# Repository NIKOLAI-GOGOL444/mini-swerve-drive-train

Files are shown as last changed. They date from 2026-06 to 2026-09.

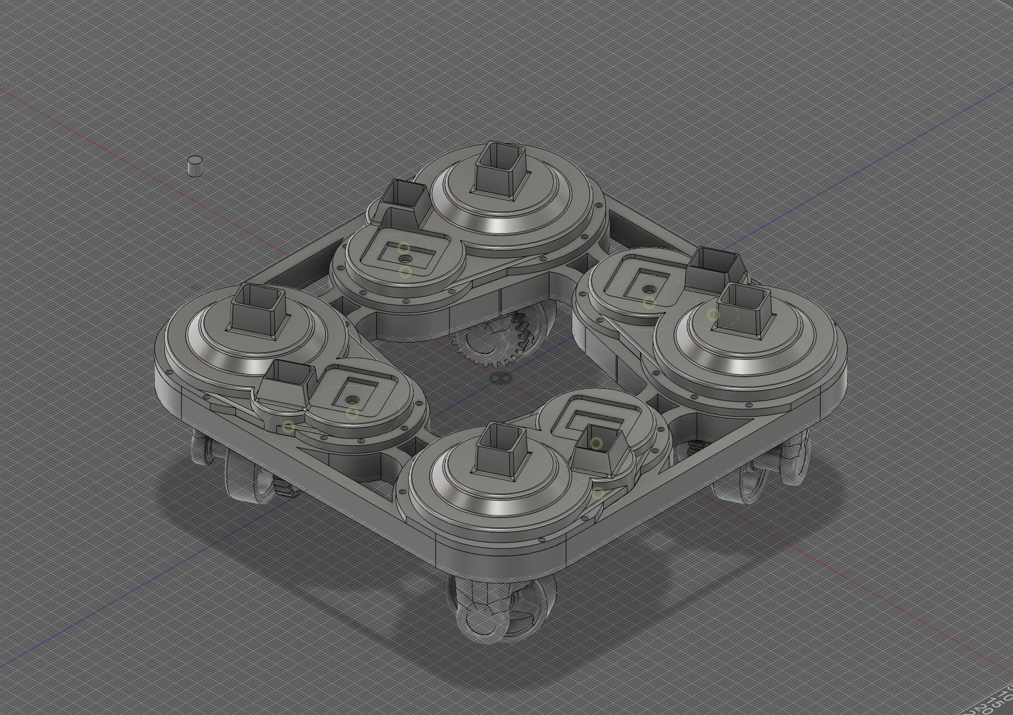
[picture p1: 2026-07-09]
images: demos/Screenshot 2026-07-07 at 9.57.56 PM.jpeg

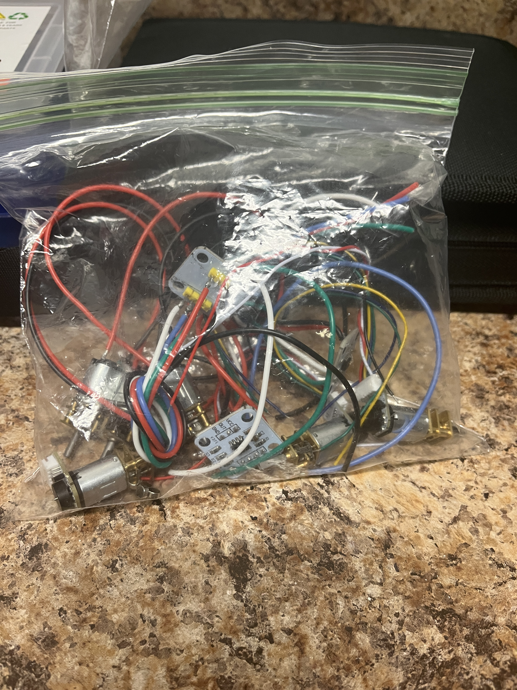
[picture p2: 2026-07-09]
images: demos/IMG_0874.jpeg

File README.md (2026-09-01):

IMPORTANT NOTE FOR OUTPOST REVIEWERS: please ignore the pcb stuff in my BOM.CSV and files and stuff. I do not have a pcb design yet, so I will not be requesting funding for that part of this project, and will request for it as a sepreate project at a later time. 
NEW NOTE: I have edited the BOM.csv file to exclude pcb stuff. 

IMPORTANT NOTE FOR HORIZONS REVIEWERS:
NOTE: i am ONLY trying to submit the CONTROLLER pcb right now. all my hours have been working on that, do not reject my project under the robot pcb stuff not being in here, thats because it isnt finished yet, ill submit that at a later date, just worry about the controller stuff. 
UPDATE: as of tuesday july 28 1:18 am, I have finished the controller pcb and uploaded the final designs file to the repo. it is now ready to be purchased.
Screenshot 2026-07-28 at 10 36 25 AM
Screenshot 2026-07-28 at 10 36 18 AM
Screenshot 2026-07-28 at 10 37 19 AM
8/31/26 UPDATE
after more work, I have resubmitted for hour aproval. since my last update to this repo, I have ordered my finished boards for manufacturing and recieved them in the mail. here are some images. I have begun assembly, first by harvesting some chips from old devboards and breakout modules. after that I hit a wall when I realized that salvaging tiny capacitors and resistors would be impossible, so now I am working on getting all my parts ordered so I can assemble. hopefully I get my hours aprovved soon so I can buy digikey grants, because that would seriously help me greatly. 




UPDATE: as of monday july 27th 11:36 pm, I have uploaded new gerbers that are of the pcb fully routed and corrected against the DRC. if wanted, the pcb could now be purchased and it would function, but the silkscreen labels would be a mess. im now going to arrange the silkscreen, then begin on the swerve drive brain pcb. 
NEW NOTE AFTER SECOND REJECTION: 
my pcb wasnt routed yet because this project is currently a work in progress. I am submitting it fairly early on because I want to qualify intime to go to horizons polaris (I have an extension to qualify until july 31st.) I have done work on my pcb and almost finished the routing, it is pretty close to done, just gotta double check everything and fix some small issues. just please understand that this pcb and its gerber files arent finsished, which explains the missing routing and anything you may find in this file. I am actively working on this project, so please give me grace with any structural errors that may be in the pcb and help me make the polaris deadline. im attaching the newer gerbers. 
my project for horizons is the pcbs that go with this robot, I am submitting them as a seperate hardware project that I will not need funding for. I am documenting my hours for the pcbs seperate from the code file I used on the robots cad and coding, however I will be using the same github for both projects just to keep things simple. so ignore all the cad and code stuff, and just look at the PCB stuff, because thats my horizons project. I am currently in the process of tracing the controller PCB, so all I have right now as I submit is the schematic and maybe a unfinished gerber file, but I will keep working on the project and add to my repo as I go. if you have any questions just reach me on the hackclub slack. 
ALSO, the BOM.CSV you see when you open my repo isnt the one for this project, that is for my outpost project. please look in my controller pcb stuff file, you will find my horizons BOM.CSV file in there. 
STEPS TO REPRODUCE:
when pcbs are finished, someone can recreate my PCBS by going online to a pcb manufacturing website, uploading the gerber files for my controller and robot control board I will eventually put in my repo, and ordering them, then either choosing to assemble the pcbs themselves or buying it preassembled. if they wanted recreate the FULL ROBOT (NOT INCLUDED WITH MY HORIZONS SUBMISSION, INCLUDING FYI) they would then flash the code in my repo to their PCBs, then 3d print the cad files with either their own 3d printer or through a manufacturing sight, assembling based off of the cad images ive attached for the project (i think I will add an assembly tutorial eventually), then plugging in batteries and then they would have my robot! 
NEWER 3D RENDERS AND PCB EDITOR SCREENSHOTS AS OF SUN JUL 26 2026
Screenshot 2026-07-26 at 7 36 01 PM
Screenshot 2026-07-26 at 7 36 13 PM
Screenshot 2026-07-26 at 7 39 59 PM

3D RENDERS (PLEASE NOTE THAT THE CONTROLLER PCB ISNT FINISHED, AND I HAVENT STARTED THE ROBOT PCB.[swervecontrollerPCBv1.pdf](https://github.com/user-attachments/files/30342656/swervecontrollerPCBv1.pdf)
Screenshot 2026-07-23 at 6 22 36 AM
Screenshot 2026-07-24 at 6 09 05 AM
Screenshot 2026-07-24 at 6 09 14 AM

hi!

im making a mini swerve drive train inspired by FRC swerve drive trains, because they just make me so happy lol.
if you cant tell already idk how to use github at all.
I hope to figure it out as I work on this project. 
if you need anything or have any questions about my project, id be happy to help! just contact me however that works on git idk.

thank you for your time,
-NIKOLAI!
# Mini Swerve Drive Train

inspired by my love of FRC swerve modules and drive trains, they're so freaking cool. 
this project is documented on forge, stardance, and horizons. 
I would most reccomend checking out stardance, because that is where this project is most actively docdumented. 
https://stardance.hackclub.com/projects/25609
ive logged around 25 hours as I write this, however I only began logging maybe two weeks ago, and in reality this project has taken MUCH much longer than that lol. 

AI declaration for hackclub

I worked with claude to turn my google docs parts list into a BOM.CSV file. I also use gemini or other chatbots to help me write code and understand data protocols. I never copy and paste exactly what is given to me without understanding what it is or why, but instead use AI as a learning tool to help me better learn and understand programming. especially as a new programmer, I am entirely self taught using online resources, and AI has been a very useful tool for my learning. 

here is a 3d demo of my cad, stl files are available in this repository. 

https://a360.co/4gOPGcb

Screenshot 2026-07-09 at 3 30 32 AM

Screenshot 2026-07-09 at 3 30 18 AM

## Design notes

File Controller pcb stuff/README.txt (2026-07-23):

the gerber files for the controller are currently unfinished! just putting them here so I can have something for horizons reviewers, will update when it is finished.

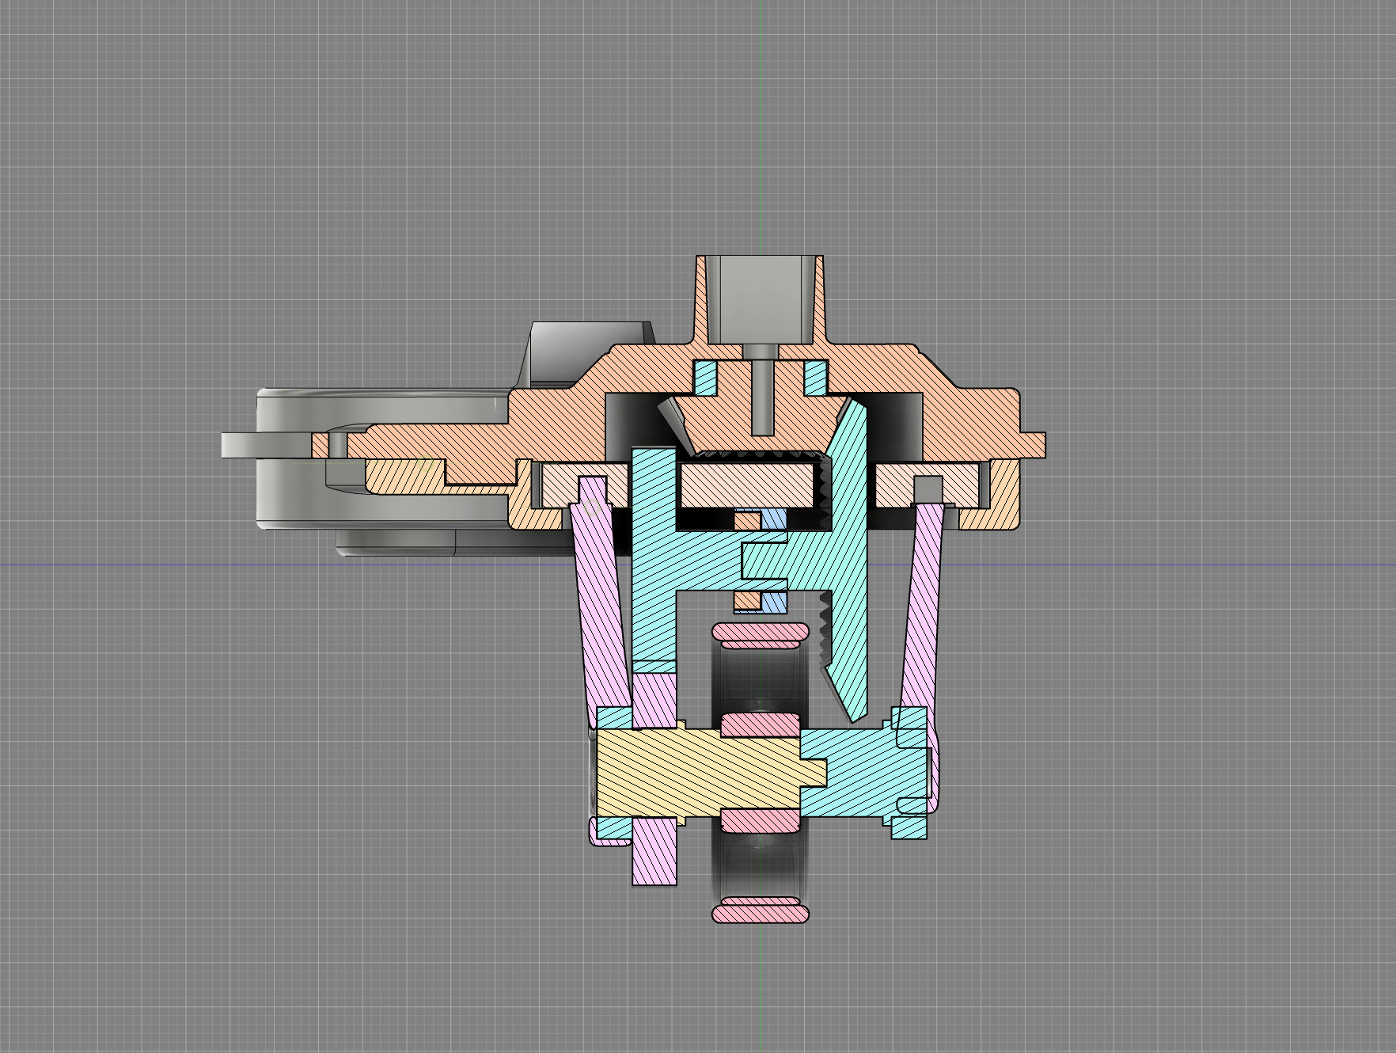
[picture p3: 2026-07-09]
images: demos/Screenshot 2026-07-06 at 1.36.42 AM.jpeg

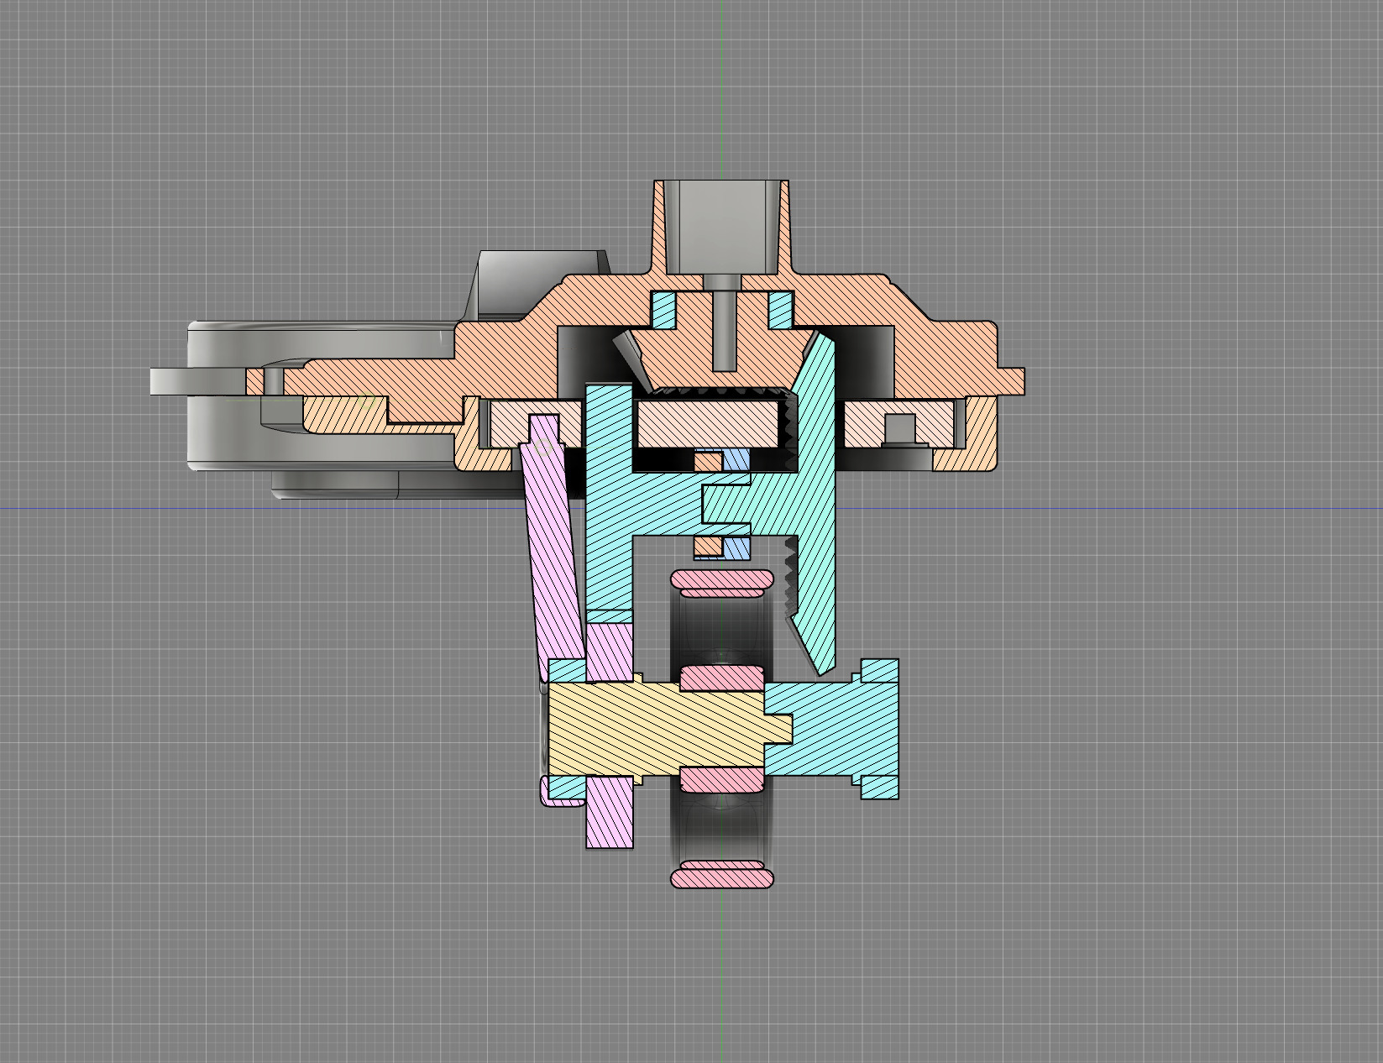
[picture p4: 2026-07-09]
images: demos/Screenshot 2026-07-06 at 1.37.23 AM.jpeg

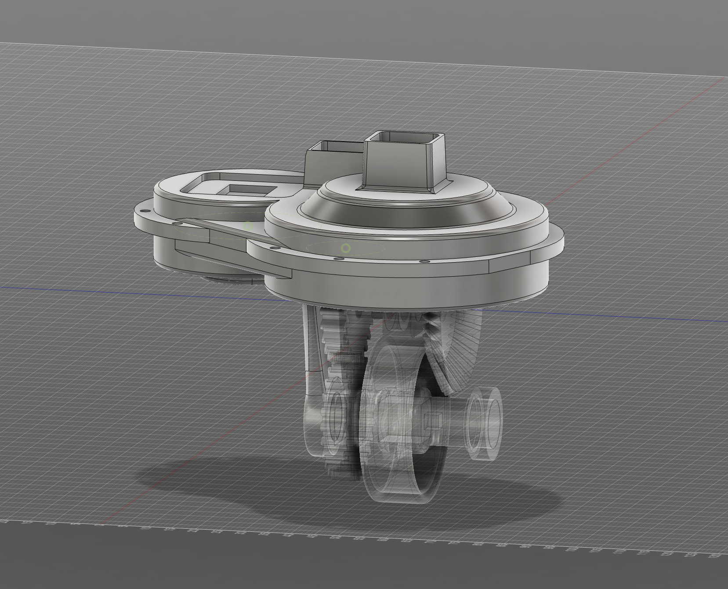
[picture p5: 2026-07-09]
images: demos/Screenshot 2026-07-06 at 1.37.53 AM.jpeg

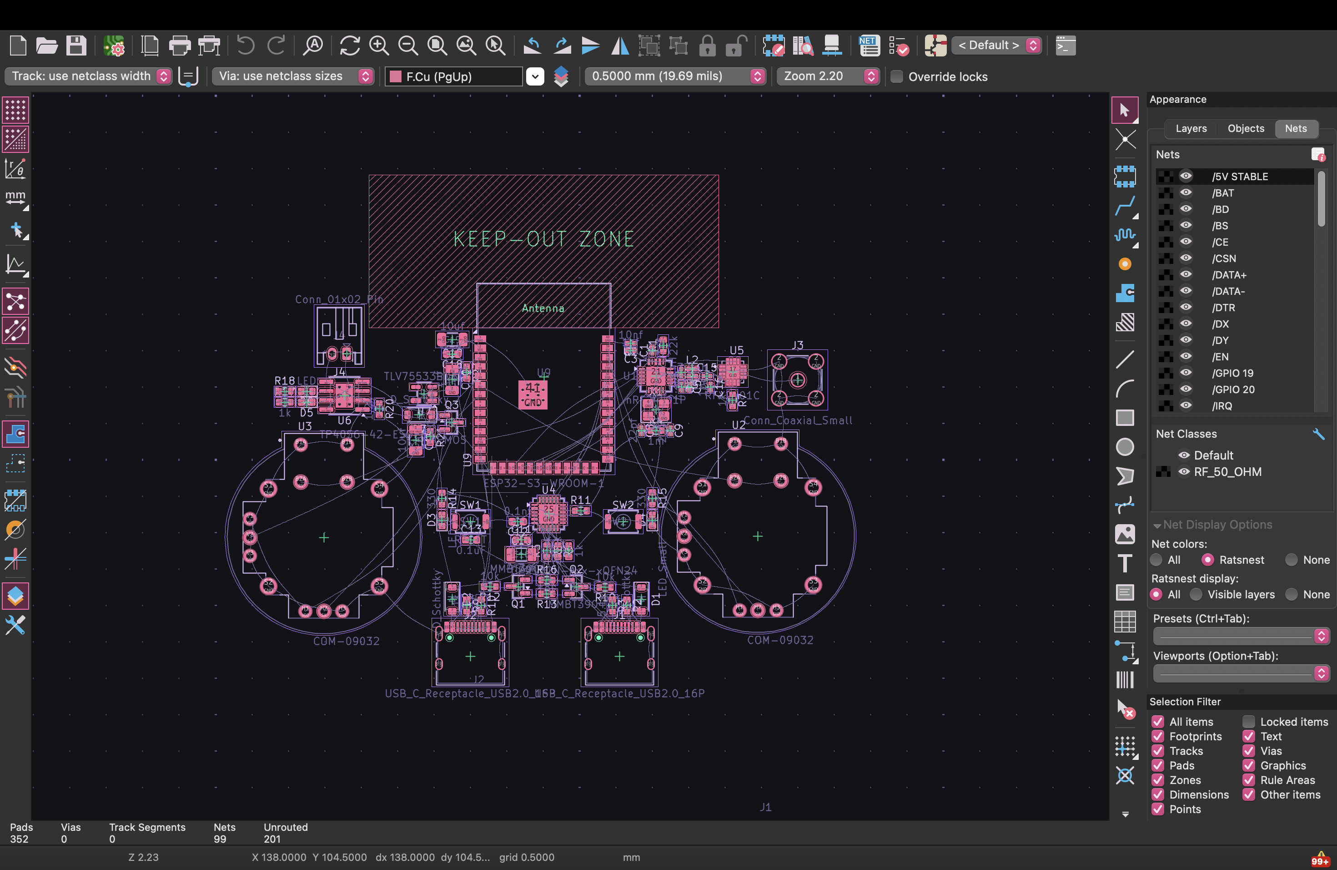
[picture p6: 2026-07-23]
Controller pcb stuff/current state of controller pcb.png

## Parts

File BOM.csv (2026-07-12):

Category | Item | Voltage | Scope | Qty | Est. Unit Price | Est. Total Price | Source Link | Notes
Compute | ESP32-S3-DevKitC-1 N16R8 dev board | 3.3V logic / 5V USB | Central x1 | 1 | 16.99 | 16.99 | https://www.amazon.com/dp/B0DKF4DSQ4 | Main controller
Sensing | TCA9548A 8-Channel I2C Multiplexer breakout | 3.3V | Central x1 | 1 | 8.49 | 8.49 | https://www.amazon.com/dp/B0FBGC5BRP | Needed since 4x steer encoders likely share default I2C address
Sensing | MPU-6050 Gyroscope/Accelerometer breakout (GY-521) | 3.3V | Central x1 | 1 | 6.99 | 6.99 | https://www.amazon.com/dp/B01DK83ZYQ | Confirm logic-out is 3.3V
Power | 7.4V 2S LiPo battery (2200-3000mAh, XT60) | 7.4V | Central x1 | 1 | 19.99 | 19.99 | (generic - link not provided) | Feeds drive+steer controllers; needs step-down to 3.3V for logic
Drive | Drive motor w/ encoder | 7.4V motor / 3.3V encoder | Per module | 4 | 12.00 | 48.00 | https://www.amazon.com/dp/B0GSJSMNC9 | Do not backfeed 3.3V encoder line into 7.4V motor leads
Drive | Drive motor controller breakout (DRV8833-class) | 7.4V in / logic PWM in | Per module | 4 | 9.99 | 39.96 | https://www.amazon.com/dp/B0DX6BNV53 | Sold as 5-pack (1 spare). Check board's logic-input voltage tolerance vs ESP32 3.3V GPIO
Steer | Steer motor | 7.4V | Per module | 4 | 9.50 | 38.00 | (Amazon cart link not resolvable) | Same controller family as drive
Steer | Steer shaft encoder breakout (AS5600-style) | 3.3V, I2C | Per module | 4 | 7.49 | 29.96 | https://www.amazon.com/dp/B0CM3C8KFT | Goes through TCA9548A mux
Bearings | 6900-2RS bearing (10x22x6mm, large) | N/A | Per module | 4 | 1.10 | 4.40 | https://www.amazon.com/dp/B0CRLFSLWP | ASSUMPTION: 1/module - confirm vs your CAD
Bearings | 10x15x4mm bearing (smaller) | N/A | Per module | 4 | 1.05 | 4.20 | https://www.amazon.com/dp/B0DJQFKSBZ | ASSUMPTION: 1/module
Bearings | MR105-2RS bearing (5x10x4mm, even smaller) | N/A | Per module | 4 | 0.85 | 3.40 | https://www.amazon.com/dp/B082PRVZ7B | ASSUMPTION: 1/module
Bearings | 7mm ID bearing, inner drive mechanism | N/A | Per module | 4 | 1.10 | 4.40 | https://www.amazon.com/dp/B0F4XYQ2KP | ASSUMPTION: 1/module
Fabrication | 3D printing filament (chassis + 4x module housings/lids) | - | Central | 1 | 25.00 | 25.00 | - | ~700g-1kg PETG/PLA, own printer

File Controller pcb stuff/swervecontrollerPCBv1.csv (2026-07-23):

Reference | Qty | Value | DNP | Exclude from BOM | Exclude from Board | Footprint | Datasheet
C1 | 1 | 33nf |  |  |  | Capacitor_SMD:C_0402_1005Metric
C2 | 1 | 10nf |  |  |  | Capacitor_SMD:C_0402_1005Metric
C3 | 1 | 1nf |  |  |  | Capacitor_SMD:C_0402_1005Metric
C4 | 1 | 2.2nf |  |  |  | Capacitor_SMD:C_0402_1005Metric
C5 | 1 | 4.7pf |  |  |  | Capacitor_SMD:C_0402_1005Metric
C8,C9 | 2 | 22pf |  |  |  | Capacitor_SMD:C_0402_1005Metric
C10 | 1 | 4.7uf |  |  |  | Capacitor_SMD:C_1206_3216Metric
C11,C18 | 2 | 0.1uf |  |  |  | Capacitor_SMD:C_0603_1608Metric
C12 | 1 | 0.1nf |  |  |  | Capacitor_SMD:C_0603_1608Metric
C13 | 1 | 0.1uF |  |  |  | Capacitor_SMD:C_0603_1608Metric
C14,C19 | 2 | 10uf |  |  |  | Capacitor_SMD:C_1206_3216Metric
C15 | 1 | 1.5pF |  |  |  | Capacitor_SMD:C_0402_1005Metric
C16 | 1 | 1pF |  |  |  | Capacitor_SMD:C_0402_1005Metric
C20 | 1 | 1uf |  |  |  | Capacitor_SMD:C_1206_3216Metric
D1,D2,D7 | 3 | D_Schottky |  |  |  | Diode_SMD:D_SOD-123
D3,D4 | 2 | LED_Small |  |  |  | LED_SMD:LED_0603_1608Metric
D5,D6 | 2 | LED |  |  |  | LED_SMD:LED_0603_1608Metric
J1,J2 | 2 | USB_C_Receptacle_USB2.0_16P |  |  |  | Connector_USB:USB_C_Receptacle_HRO_TYPE-C-31-M-12 | https://www.usb.org/sites/default/files/documents/usb_type-c.zip
J3 | 1 | Conn_Coaxial_Small |  |  |  | Connector_Coaxial:SMA_Amphenol_901-144_Vertical
J4 | 1 | Conn_01x02_Pin |  |  |  | Connector_JST:JST_PH_S2B-PH-K_1x02_P2.00mm_Horizontal
L1 | 1 | 8.2nH |  |  |  | Inductor_SMD:L_0402_1005Metric
L2 | 1 | 2.7nh |  |  |  | Inductor_SMD:L_0402_1005Metric
L3 | 1 | 3.9nh |  |  |  | Inductor_SMD:L_0402_1005Metric
Q1,Q2 | 2 | MMBT3904 |  |  |  | Package_TO_SOT_SMD:SOT-23 | https://www.onsemi.com/pdf/datasheet/pzt3904-d.pdf
Q3 | 1 | PMOS |  |  |  | Package_TO_SOT_SMD:SOT-23 | https://ngspice.sourceforge.io/docs/ngspice-html-manual/manual.xhtml#cha_MOSFETs
R1 | 1 | 22k |  |  |  | Resistor_SMD:R_0603_1608Metric
R2,R3,R9,R10 | 4 | 5.1k |  |  |  | Resistor_SMD:R_0603_1608Metric
R4 | 1 | 1m |  |  |  | Resistor_SMD:R_0603_1608Metric
R5 | 1 | 22.1k |  |  |  | Resistor_SMD:R_0603_1608Metric
R6 | 1 | 47.5k |  |  |  | Resistor_SMD:R_0603_1608Metric
R7,R8,R17,R18 | 4 | 1k |  |  |  | Resistor_SMD:R_0603_1608Metric
R11,R12,R13,R16,R19,R23 | 6 | 10k |  |  |  | Resistor_SMD:R_0603_1608Metric
R14,R15 | 2 | 330 |  |  |  | Resistor_SMD:R_0603_1608Metric
R20 | 1 | 1.2k |  |  |  | Resistor_SMD:R_0603_1608Metric
R21 | 1 | 100k |  |  |  | Resistor_SMD:R_0603_1608Metric
SW1 | 1 | RESET |  |  |  | Button_Switch_SMD:SW_Push_SPST_NO_Alps_SKRK
SW2 | 1 | BOOT |  |  |  | Button_Switch_SMD:SW_Push_SPST_NO_Alps_SKRK
U1 | 1 | nRF24L01P |  |  |  | Package_DFN_QFN:QFN-20-1EP_4x4mm_P0.5mm_EP2.5x2.5mm | http://www.nordicsemi.com/eng/content/download/2726/34069/file/nRF24L01P_Product_Specification_1_0.pdf
U2,U3 | 2 | COM-09032 |  |  |  | COM-09032:XDCR_COM-09032
U4 | 1 | CP2102N-Axx-xQFN24 |  |  |  | Package_DFN_QFN:QFN-24-1EP_4x4mm_P0.5mm_EP2.6x2.6mm | https://www.silabs.com/documents/public/data-sheets/cp2102n-datasheet.pdf
U5 | 1 | RFX2401C |  |  |  | RFX2401C:QFN50P300X300X60-17N
U6 | 1 | TP4056-42-ESOP8 |  |  |  | Package_SO:SOIC-8-1EP_3.9x4.9mm_P1.27mm_EP2.41x3.3mm_ThermalVias | https://www.lcsc.com/datasheet/lcsc_datasheet_2410121619_TOPPOWER-Nanjing-Extension-Microelectronics-TP4056-42-ESOP8_C16581.pdf
U7 | 1 | TLV75533PDBV |  |  |  | Package_TO_SOT_SMD:SOT-23-5 | http://www.ti.com/lit/ds/symlink/tlv755p.pdf
U9 | 1 | ESP32-S3-WROOM-1 |  |  |  | RF_Module:ESP32-S3-WROOM-1 | https://www.espressif.com/sites/default/files/documentation/esp32-s3-wroom-1_wroom-1u_datasheet_en.pdf
X1 | 1 | 16mhz |  |  |  | Crystal:Crystal_SMD_3225-4Pin_3.2x2.5mm

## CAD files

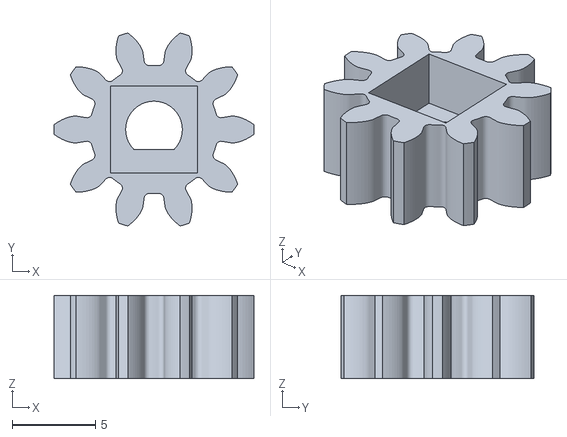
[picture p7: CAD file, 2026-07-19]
swerves v6/fixed 10t.stl
12.0 x 11.6 x 5.00

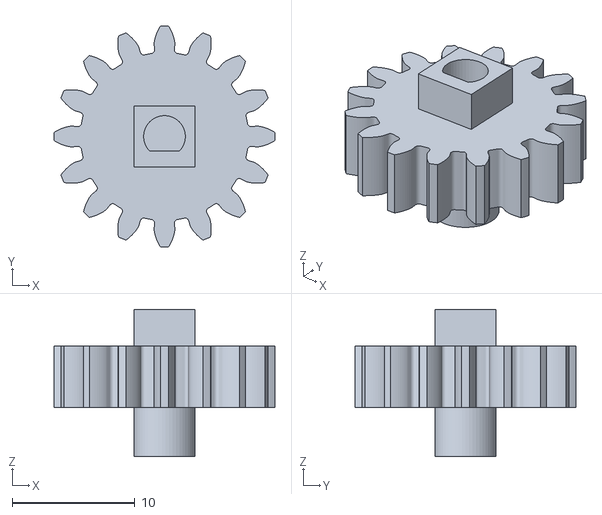
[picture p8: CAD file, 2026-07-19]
swerves v6/16t fixed.stl
18.0 x 18.0 x 12.0

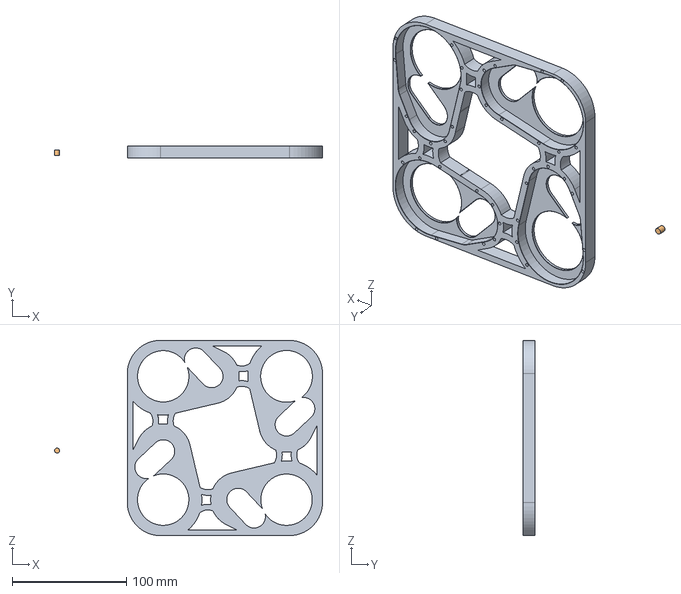
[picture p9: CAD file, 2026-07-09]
swerves v6/chasiss v1.step
234.7 x 10.5 x 171.0 mm

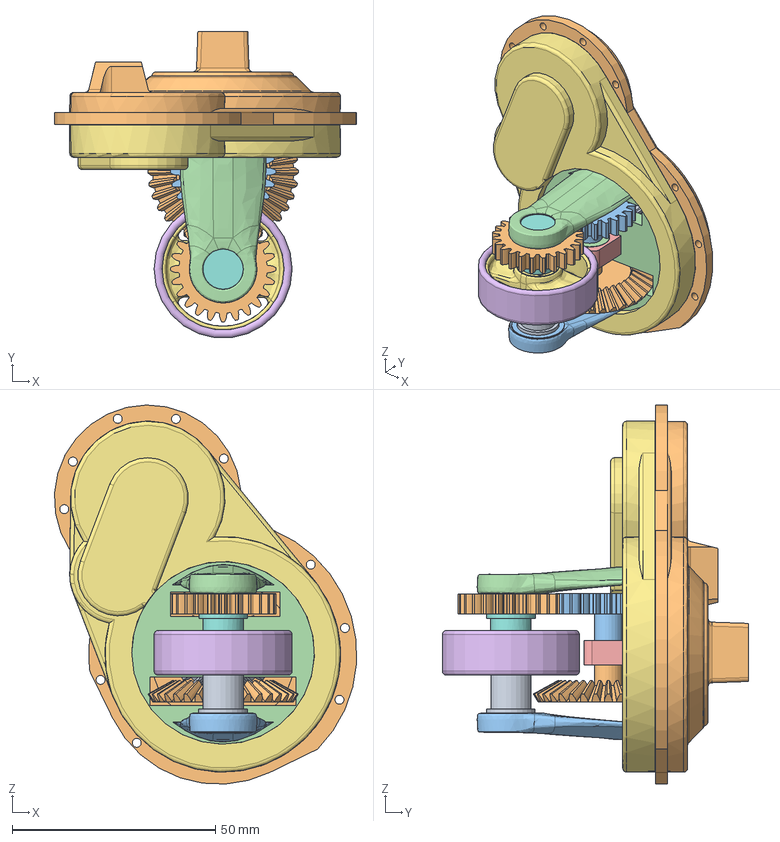
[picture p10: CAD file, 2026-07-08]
swerves v6/REAL swerves V6.step
74.4 x 75.4 x 93.3 mm

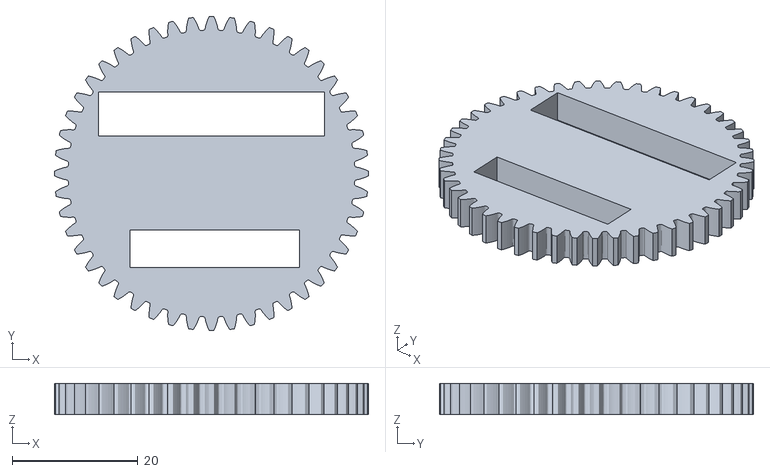
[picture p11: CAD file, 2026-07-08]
swerves v6/48t steer V^.stl
50.0 x 50.0 x 5.00

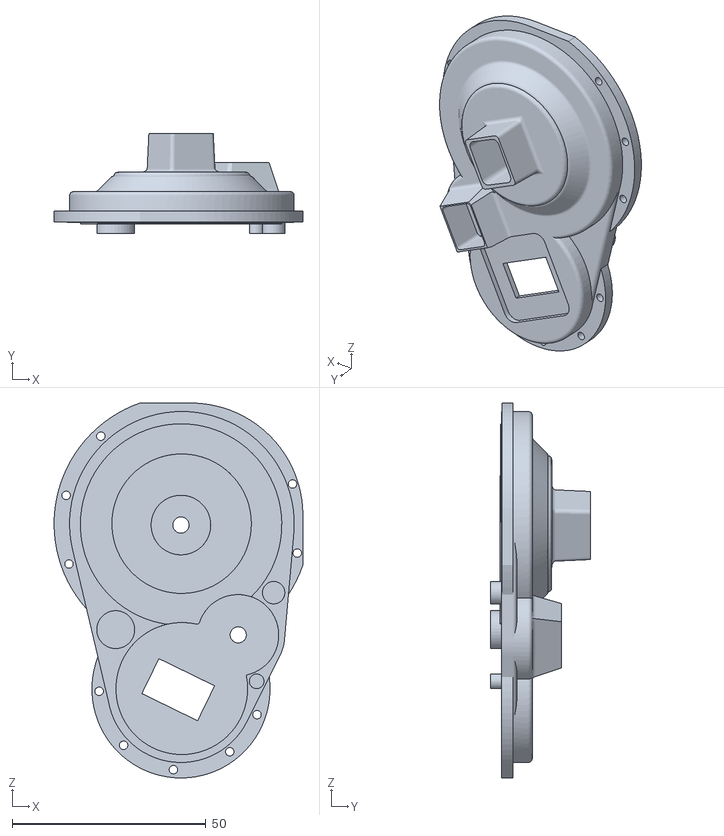
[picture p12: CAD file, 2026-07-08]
swerves v6/top shell v6.stl
64.2 x 25.8 x 96.8

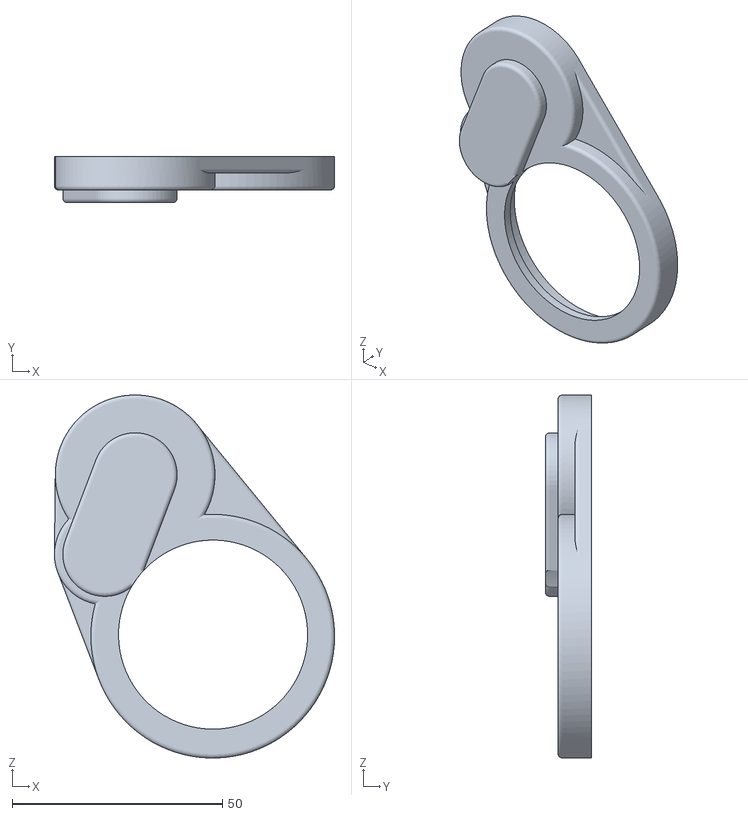
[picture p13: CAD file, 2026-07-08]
swerves v6/bottom shell swerves v6.stl
66.7 x 11.0 x 86.4

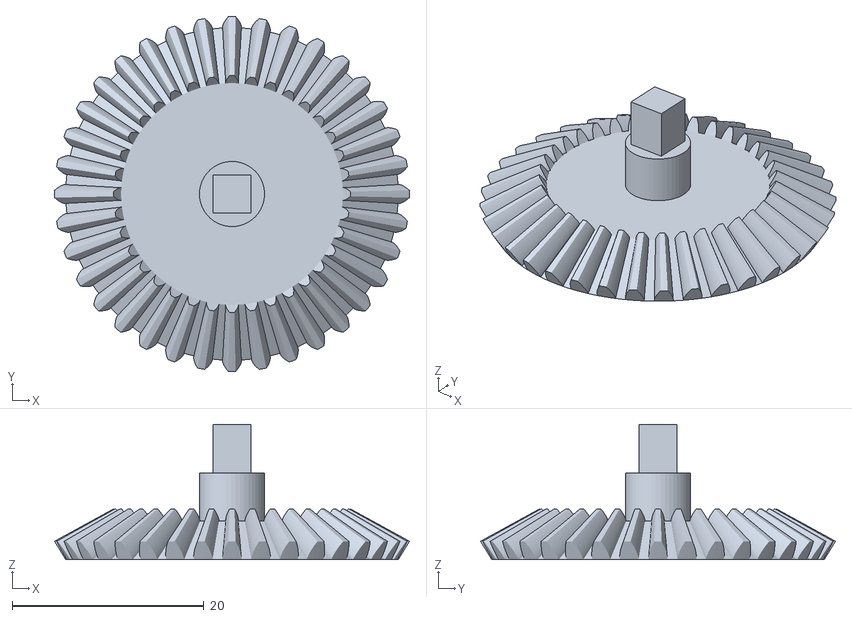
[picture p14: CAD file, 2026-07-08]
swerves v6/updated 36t gear.stl
37.0 x 37.0 x 14.1

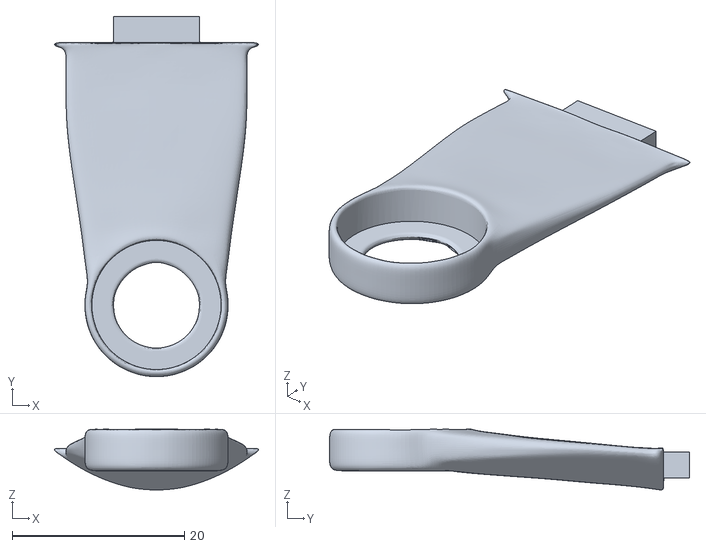
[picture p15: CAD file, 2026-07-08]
swerves v6/stick 2 V6.stl
23.7 x 41.8 x 7.07

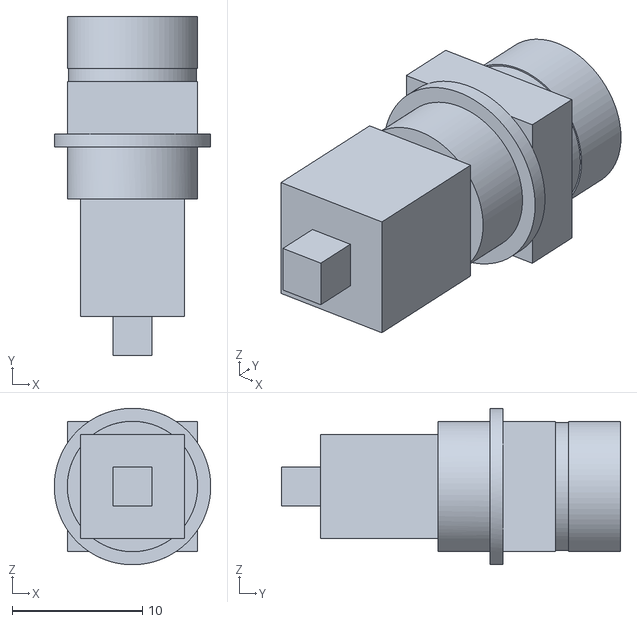
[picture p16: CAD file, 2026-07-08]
swerves v6/drive tube peg v6.stl
12.0 x 26.0 x 12.0

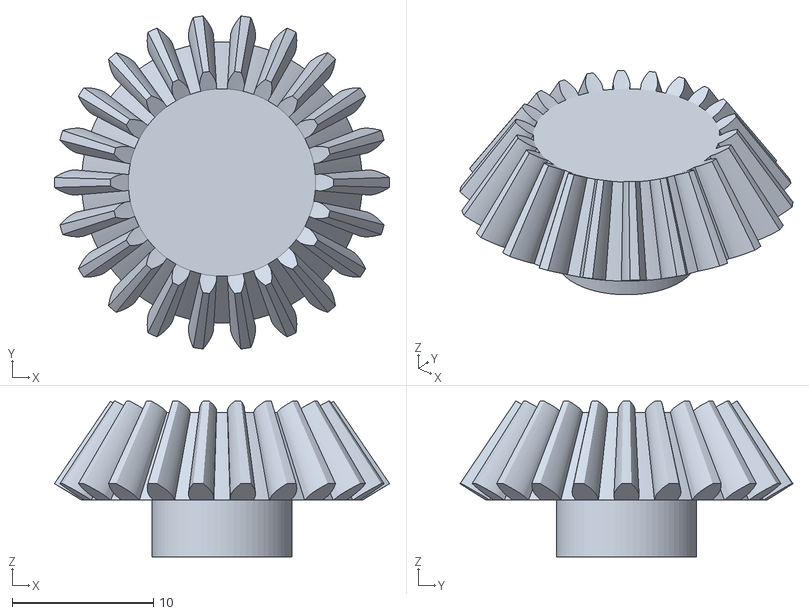
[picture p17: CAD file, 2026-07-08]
swerves v6/22tt.stl
23.7 x 23.6 x 11.0

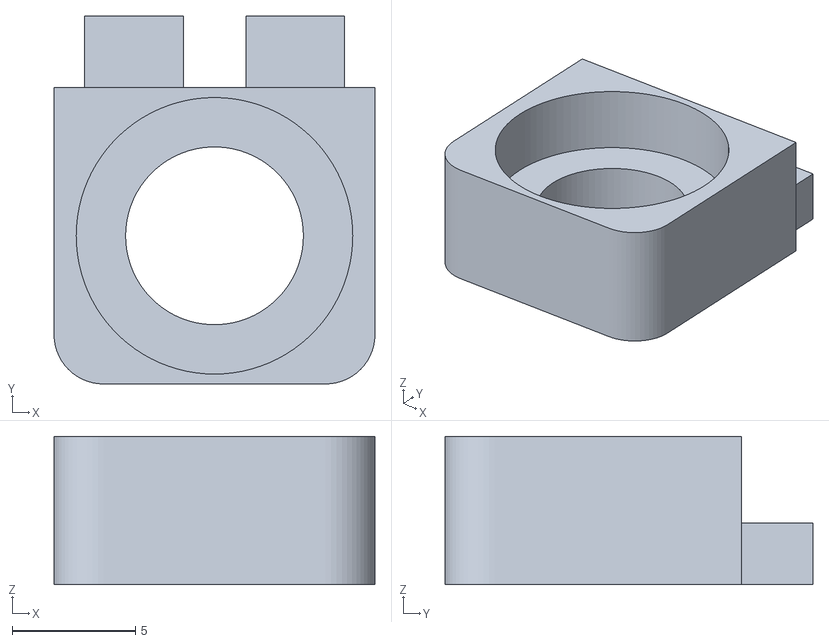
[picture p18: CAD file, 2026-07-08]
swerves v6/hole v3.stl
13.0 x 14.9 x 6.00

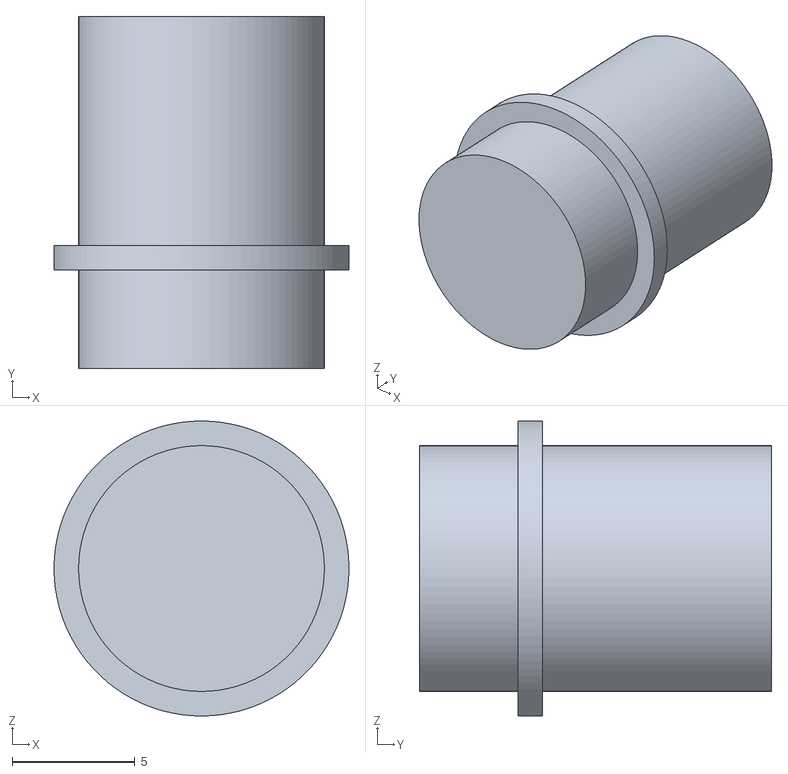
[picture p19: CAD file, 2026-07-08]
swerves v6/drive tube hole v6.stl
12.0 x 14.3 x 12.0

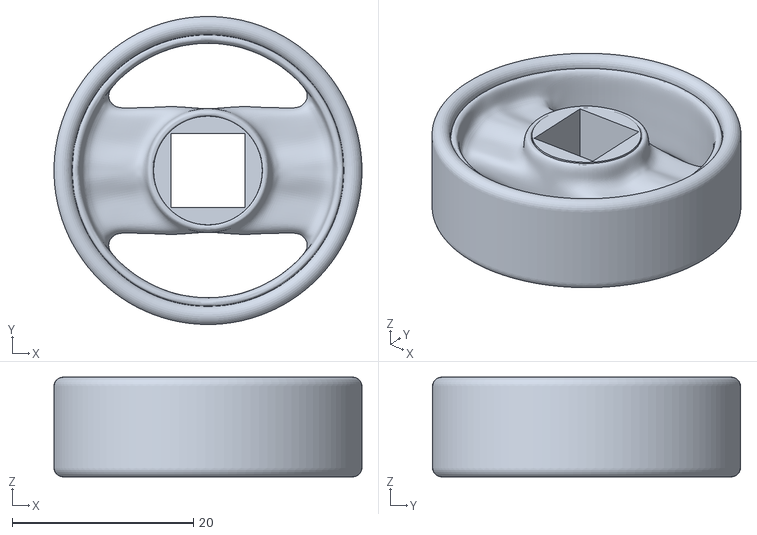
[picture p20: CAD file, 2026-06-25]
swerves v6/wheel v6.stl
34.0 x 34.0 x 11.0

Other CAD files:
swerves v6/stick v6.stl
swerves v6/drive attached gear v6.stl
swerves v6/16t v6.stl
swerves v6/30t v6.stl
swerves v6/10t v6.stl
swerves v6/REAL swerves V6.stl

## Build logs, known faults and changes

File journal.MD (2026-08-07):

all logs from forge that predate my stardance documentation are here! if you want to see more recent logs, please visit my stardance page. the link to that is in the readme.md file. 

FOR HORIZONS REVIEWERS
https://lapse.hackclub.com/user/@nikolai_gogol444
that is the link to my lapse page. all pcb time lapses are easily found beacause they are conviniently named. the EARLIEST time lapse that Is part of my horizons project and is documented on the code file that I am attaching my horizons time lapses to is schematic design from july 20, 2026 at 3:22am. any timelapse that predates that Is asociated with my stardance project and can be ignored. I Will start documenting journal entries for my horizons project here.
ENTRY 2 FRIDAY AUG 7
NOTE: for some reason images arent working right now, I will update my repo later with images of the pcbs, all my files are in though
alot of work since my last entry! after tracing the 50 ohm traces on my controller, I ran it against the DRC and fixed any issues that came up, then I organized the silkscreens, and added some decals! here is the finished pcb design, that is available in the controller pcb stuff file. 
for some reason I cannot paste the image, so I will be putting images in their respective files.
after that, I began working on the controller pcb. I reused the schematic for my controller, then deleted the joysticks and battery setup, and kept the things like the rf schematic that I would need for my controll pcb. this pcb required me to keep within a tight 52 by 52 mm square in order to fit in the chasis of my robot. I acheived this by being clever with part placement, optimizing my esp chips pinout and using the backside of my pcb. my pcb includes a mpu6050, a tca multiplexer, test points to connect to my motors and encoders, drv8833 motor drivers, usbc ports for serial data and flashing, and a charge system that allows power to come from either the battery or the usbc ports, and steps down some of that voltage to 3.3v to run logic parts. I used a 4 layer pcb to better isolate the rf signal, and allow for two signal planes. I plan to purchase these pcbs from pcbbuy using my own money when I get the chance. 

ENTRY 1:
I didnt know I was supposed to do journal entries, so Ill do one big one here to document the past 3 or so days of pcb work, and go consistently from there.
I first began by doing a quick 20 minute KICAD tutorial video, as I do before using any new software, to figure out how to use it. then, I just kind of began working and learning the software on the way. I started by looking up schematics for the breakout boards that I had used to breadboard my project, so I could figure out what chips and components id need. I then went to the data sheet for the chips and replicated the ideal pcb setups shown in each datasheet on my board, and using google gemini for input and questions as I went. I wouldnt reccomend entirely trusting AI to help with pcb design, because It was very hard getting the AI to interpret my schematic correctly, and it would identify things that were perfectly fine as errors, vice versa. after that, I had a complete controller schematic with two joysticks, a 2.4ghz RF system based on the NRF24L01 PA LNA breakout board, a power distribution system that charges a 3.7v li po battery from onboard usbc ports I included for charging, serial data and code flashing, and powers the board using said battery, and boot and reset buttons. a picture of my schematic is available in the controller pcb stuff file. 
I then went to begin routing, when I got some errors, which I eventually solved by adding pads that were missing in the schematics, usually EPADs and ground pads, and routing them to where they were supposed to go, and changing my ESP32 S3 WROOM N16R8 schematic to the generic ESP32 S3 WROOM 1 schematic, which was identical to the custom footprint I got on the internet and was native to KICAD, which fixed the errors. I then began organizing my components on the board, and today I will be designing the trace on the RF stuff on the board to have exactly 50 OHMs of resistance and routing all my components, new entry coming soon. 

# 2026-06-25: some pretty important CAD fixes, and a chasis!

hi! I finally did the final changes on CAD, im pretty sure, ill know if theyre perfect when I print the fixed parts, should work though cad looks good. 

I fixed the CAD issues previously stated in a earlier post, which included the uncentered bevel gear, loosely meshed drive gears, and loosely meshing bevel gear in the drive system. all the gears in fusion mesh properly now, and the meshing is good in the drive bevel system at all rotations, I just made sure. Im going to update the GITHUB fusion files. 

also, I made a chasis for my swerve modules. its made to be pretty lightweight, as this whole project is, Im trying to stay under 3lbs. one swerve module including electronics is 3.7 oz, and the chasis is 2.1 oz, so im well below that weight limit currently. I will also include the chasis in the new    CAD update. 
Screenshot 2026-06-25 at 12.38.27 AM.png

Screenshot 2026-06-25 at 12.35.18 AM.png

# 2026-06-17: origins

I thought it would be a good idea to mention how I started this project, as I only started documenting it here once I heard about this website. my first steps were going to the fab shop at robotics club, and looking at swerve modules, aswell as taking photos and videos. I moved around the wheel and rolled it, to get a better understanding of the mechanisms that allowed for the consecutive steering and driving. I also refrenced 3d models online, and I defenitley reccomend checking out NERDSPARK 9312s nerd swerve modules, their ingenious idea of using two gear sets with the same ratio, but one smaller than the other, to create a equal spinning motion the encoders could measure, is truly revolutionary. prior to cadding my modules, I chose electronics based off of what would be found on a real frc bot, that were also cost effective. I also plan to design a pcb when I have a complete breadboarded system, and plan to keep these parts for breadboarding. 

heres the part list for those who are curious.

esp32 s3 3.3v(3pcs ESP32-S3-DevKitC-1-N16R8 Development Board Integrated 2.4GHz WiFi Bluetooth 5.0 ESP32-S3-WROOM-1 Microcontroller Processor Dual Type C Interface for Arduino)

drive controllers 7.4v (5PCS DC DRV8833CPWR Motor Drive Board 2 Channel 3-10V 1.5A H Bridge DC Gear Motor Driver Controller Small Volume Board for DIY Projects)

drive motors 7.4v from controllers for motors, 3.3v for encoders (FABULETTA 2 Pack N20 Encoder DC Gear Motor 6V Metal High Torque D-Shaft for Robotics GA12-N20 Replacement 160-3000RPM Reduction(500RPM))

steer motors 7.4v from controllers(4X JA12-N20 Model DC 12V 100RPM Torque Mini Motor Silver+Gold)

steer shaft encoders 3.3v(WWZMDiB 4Pcs AS5600 Magnetic Encoder 3.3V 12bit high Precision Magnetic Induction Angle Measurement Sensor Module，Mainly Used to Obtain Information Such as Progressive Motor Speed)

breakout board 3.3v(PCA9548A TCA9548A I2C IIC 8-Channel Multiplexer Breakout Board - 1.65-5.5V 400KHz for Arduino, Address 0x70-0x77)

Gyroscope 3.3v(HiLetgo GY-521 MPU-6050 MPU6050 3 Axis Accelerometer Gyroscope Module 6 DOF 6-axis Accelerometer Gyroscope Sensor Module 16 Bit AD Converter Data Output IIC I2C for Arduino)

Bearings(6900-2RS Deep Groove Bearings, ID 10mm x OD 22mm x Width 6mm Double Rubber Sealed Ball Bearings, Pre-Lubricated (GCr15) Chrome Steel 4pcs)

smaller bearings(20Pcs 6700ZZ Deep Groove Ball Bearings, 10x15x4mm Double Metal Shielded Ball Bearing Chrome Steel P0 Z2, Thin Section Miniature Skateboard Bearings for Industrial Machine, Power Tools)

even smaller bearings(uxcell MR105-2RS Deep Groove Ball Bearings 5mm Inner Dia 10mm OD 4mm Bore Double Sealed Chrome Steel Blue Seal Z2 20pcs)

bearings for inner drive mechanism (uxcell 12Pcs MR117ZZ Small Bearing, 7mm ID 11mm OD 3mm Width Double Shielded Deep Groove Ball Bearings for Electric Motor Skateboards 3D Printer, (ABEC 5))

7.4v lipo battery



# 2026-06-16: code modifications!

after coding the motors to move with joystick input, I came across some issues:

- motors getting too hot
- motors moving when joystick isnt touched
- severe delay between joysticks and motor movement. 

after working with gemini, I was able to solve these issues. 

- setting the motor frequency to 2000 prevented overheating
- first, I calculated the average displacement of the joysticks from the center, when untouched. I used these calculations to create a range, and then programmed my joysticks to output a reading of 2048 when within this range. that helped alot, but I still saw some movement when untouched. I then added cubic math to my motor output, replacing the linear mapping I had previously. this scales the motor movement to a cubic function, this combination eliminated any motor movement when joysticks werent touched.

-to fix the great delay between my joysticks and motors, I did a few changes in my code. 
  - added watchdog timers, to ignore data that takes more than 10 miliseconds to return, to prevent 12c jams. 
  - moved my joystick and motor function calls to the top of my 
    loop function so they would be prioritized
  - changed the read frequency of my sensors to every 50                   
    miliseconds and print frequecy of my serial monitor to every  
    250 miliseconds.
these changes cleaned up my 12c bus, which allowed the important data needed for motor decisions to happen much more efficiently, which reduced the delay to an unoticeable ammount. Im intrested to see how else I will have to alter the 12c bus to reduce delay when I incorperate my radio reciever and transmitter for joystick to robot communication. 
Screenshot 2026-06-16 at 12.28.41 AM.png
Screenshot 2026-06-16 at 12.28.50 AM.png

![Screenshot 2026-06-16 at 12.28.54 AM.png]
(https://cdn.hackclub.com/019ecec4-96c8-762d-a563-3aacbec99962/Screenshot%202026-06-16%20at%2012.28.54%E2%80%AFAM.png)

# 2026-06-16: breadboarding, coding, and cad problems!

I began to breadboard the electronics for my swerve modules, and I also did some coding to get them to work. code screenshots coming soon. after assembling v5 of my swerves, I unfortunatley discovered that my gears were skipping and were unable to drive when rotated at some points. after inspecting my cad file, I discovered that my bevel gear was not perfectly centered, and my two gears that translate that bevel motion to spin the wheel werent meshing close enough. oops!! so, yesterday I fixed the cad, But I plan to use autodesk's motion features to test my gears before printing, to save materials and time :-). I also want to look into methods of reducing friction, to achieve higher speeds. I want this thing to be super fast lol. [Screenshot 2026-06-15 at 11.27.08 PM.png](https://cdn.hackclub.com/019ece78-a1a3-7471-b8bf-baedbc948f1d/Screenshot%202026-06-15%20at%2011.27.08%E2%80%AFPM.png)Screenshot 2026-06-15 at 11.26.52 PM.png

# 2026-06-10: swerve module cad V5 done!

after 5 versions, the cad is finally ready to print! (for software and breadboarding atleast, will make changes to the housing later so i can attach it to a chasis, once I know how big my pcb will be.) STL files are available on the github repository. will start on software and breadboarding shortly!!![Screenshot 2026-06-09 at 10.08.25 PM.png](https://cdn.hackclub.com/019eaf53-339b-7378-833b-d1d1aa4056f7/Screenshot%202026-06-09%2

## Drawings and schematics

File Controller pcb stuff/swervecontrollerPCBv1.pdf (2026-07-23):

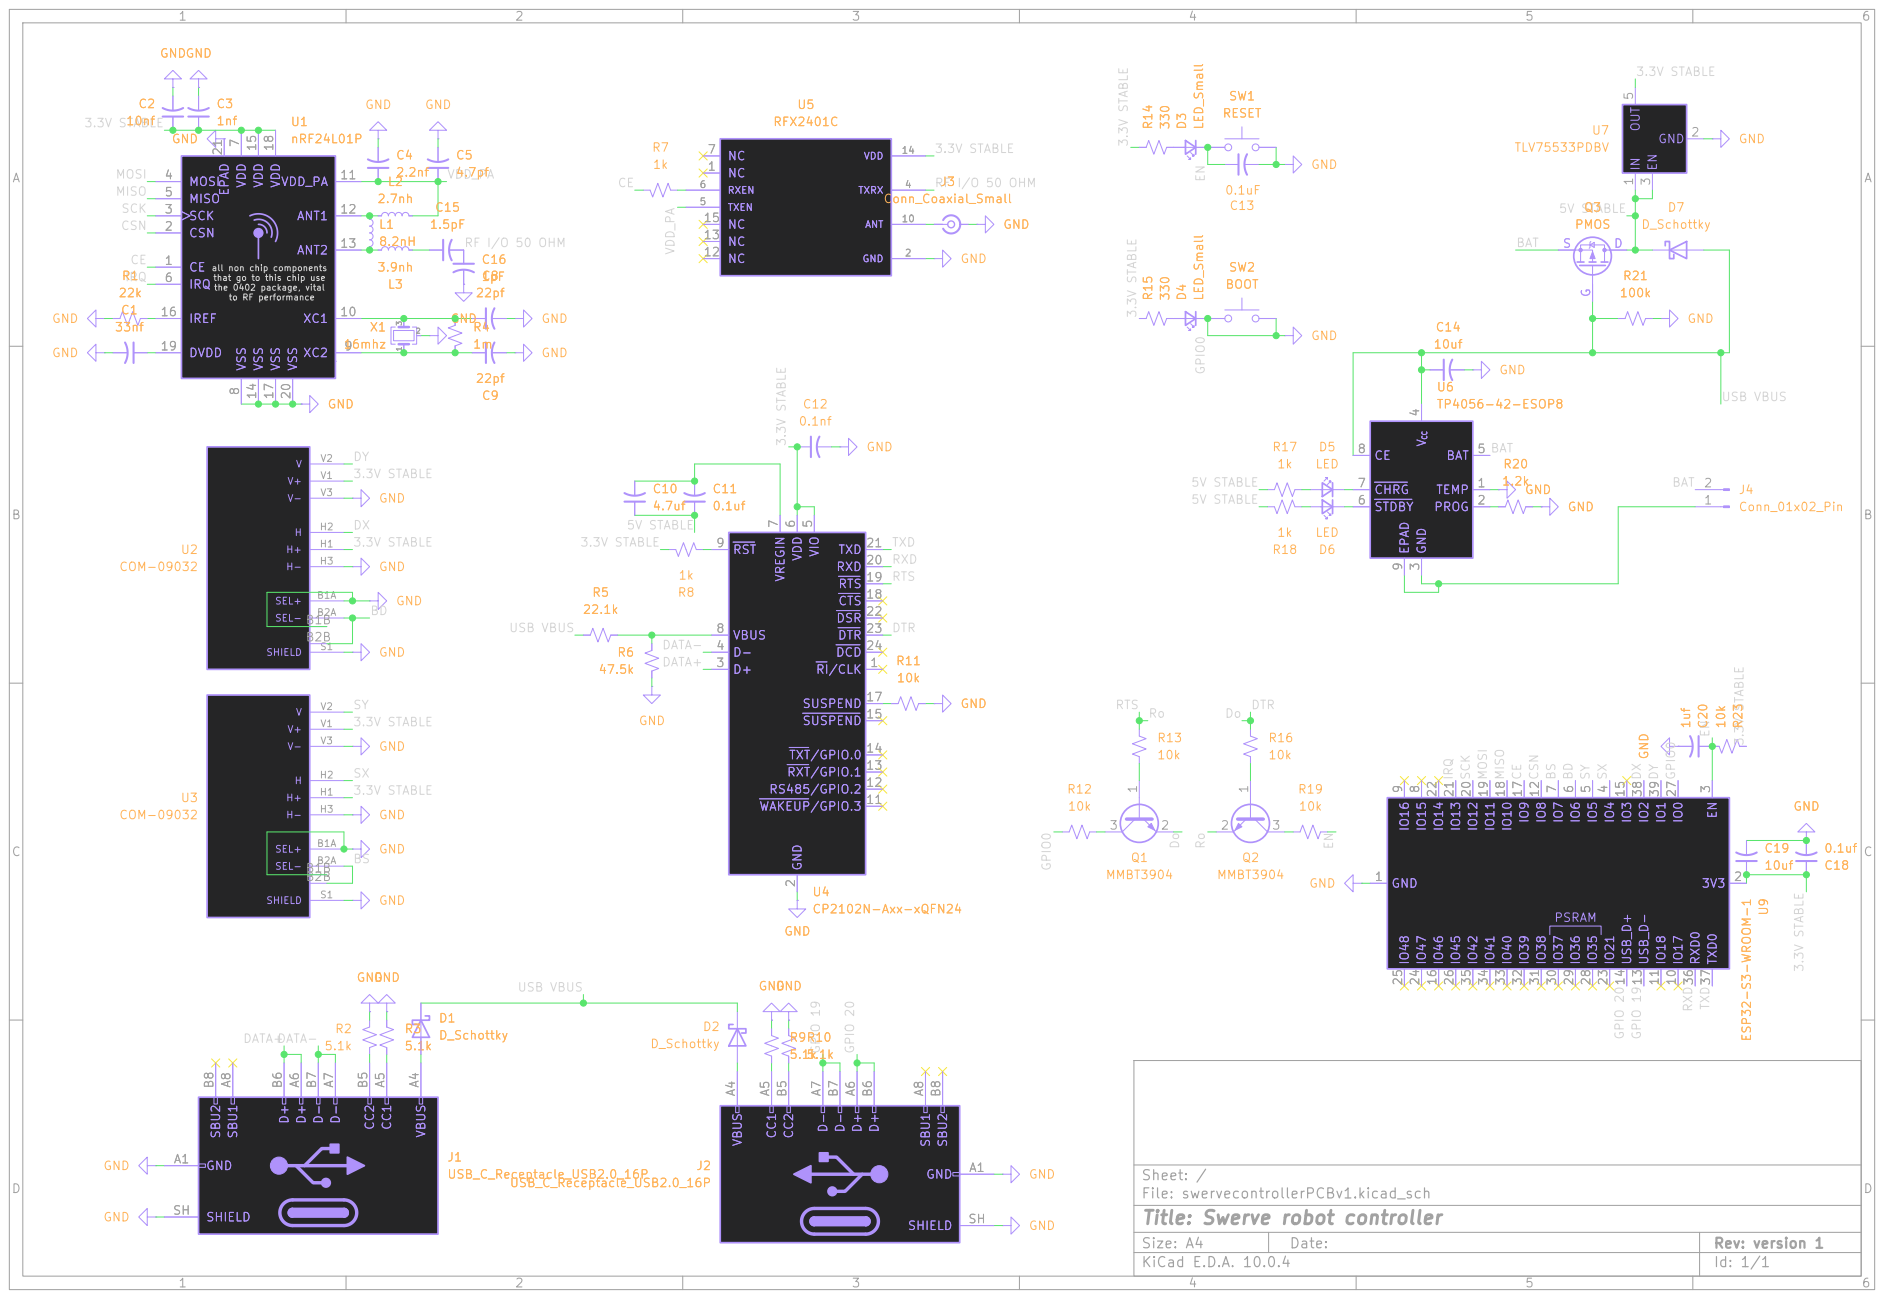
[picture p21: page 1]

all non chip components
that go to this chip use
the 0402 package, vital

6 VREGIN
SUSPEND 15 SUSPEND 17 CTS 18 RTS 19 RXD 20 TXD 21 DSR 22 DTR 23 DCD 24 R11

Sheet: /
File: swervecontrollerPCBv1.kicad_sch
Title: Swerve robot controller

Size: A4 | Rev: version 1
KiCad E.D.A. 10.0.4 | Id: 1/1

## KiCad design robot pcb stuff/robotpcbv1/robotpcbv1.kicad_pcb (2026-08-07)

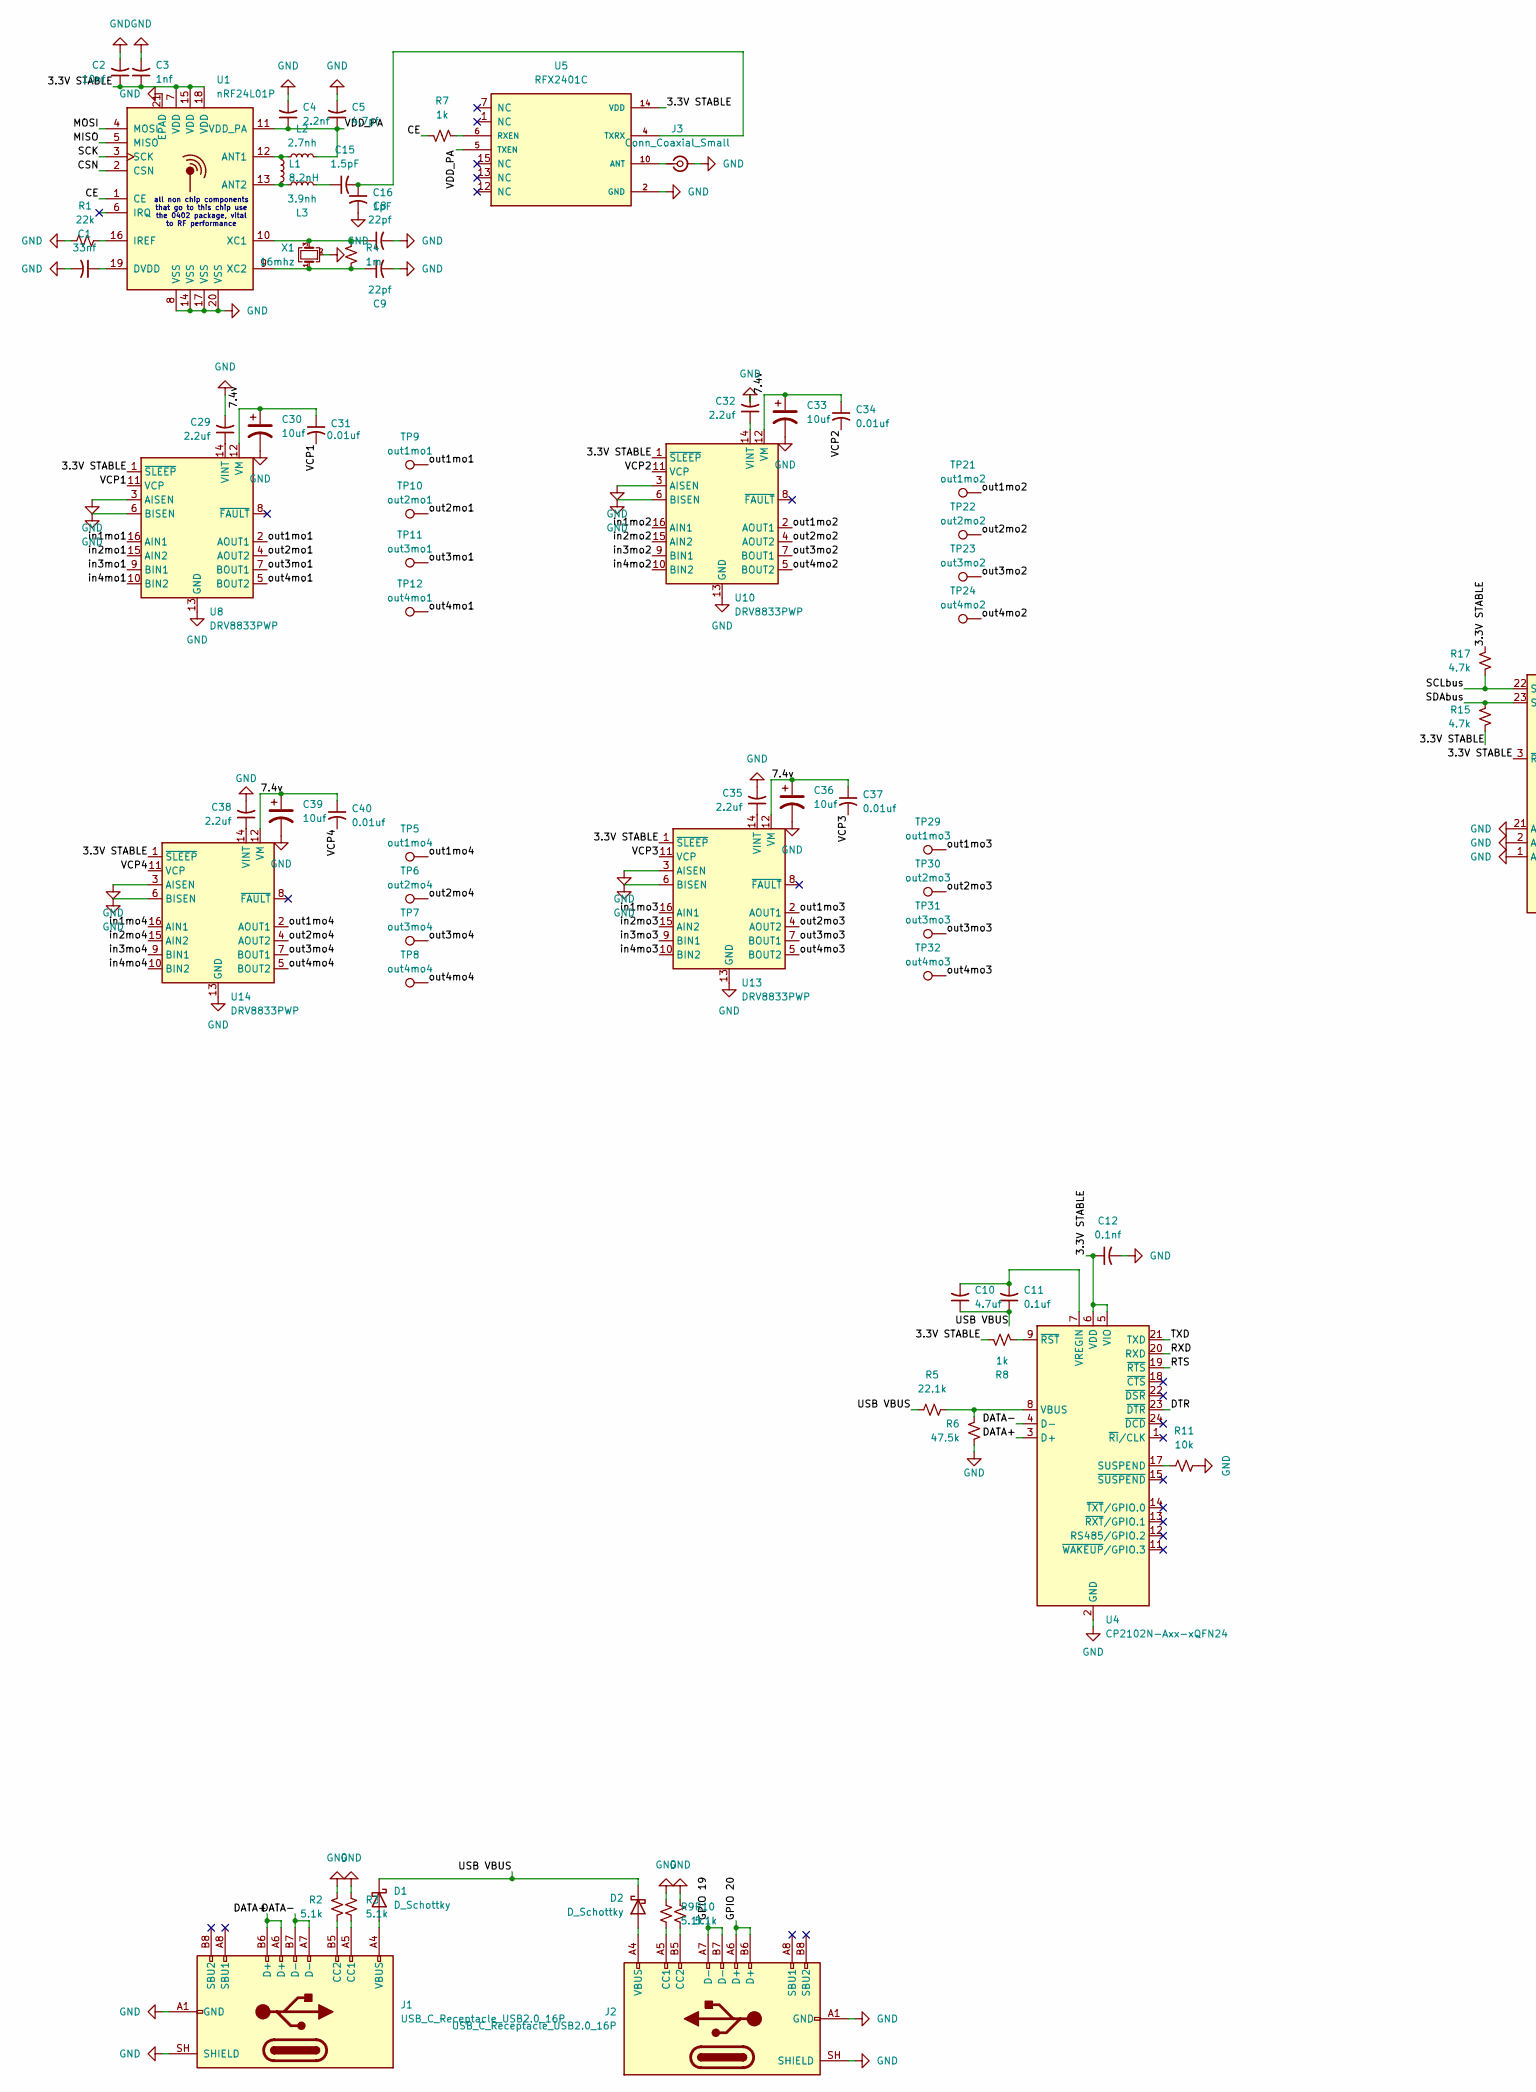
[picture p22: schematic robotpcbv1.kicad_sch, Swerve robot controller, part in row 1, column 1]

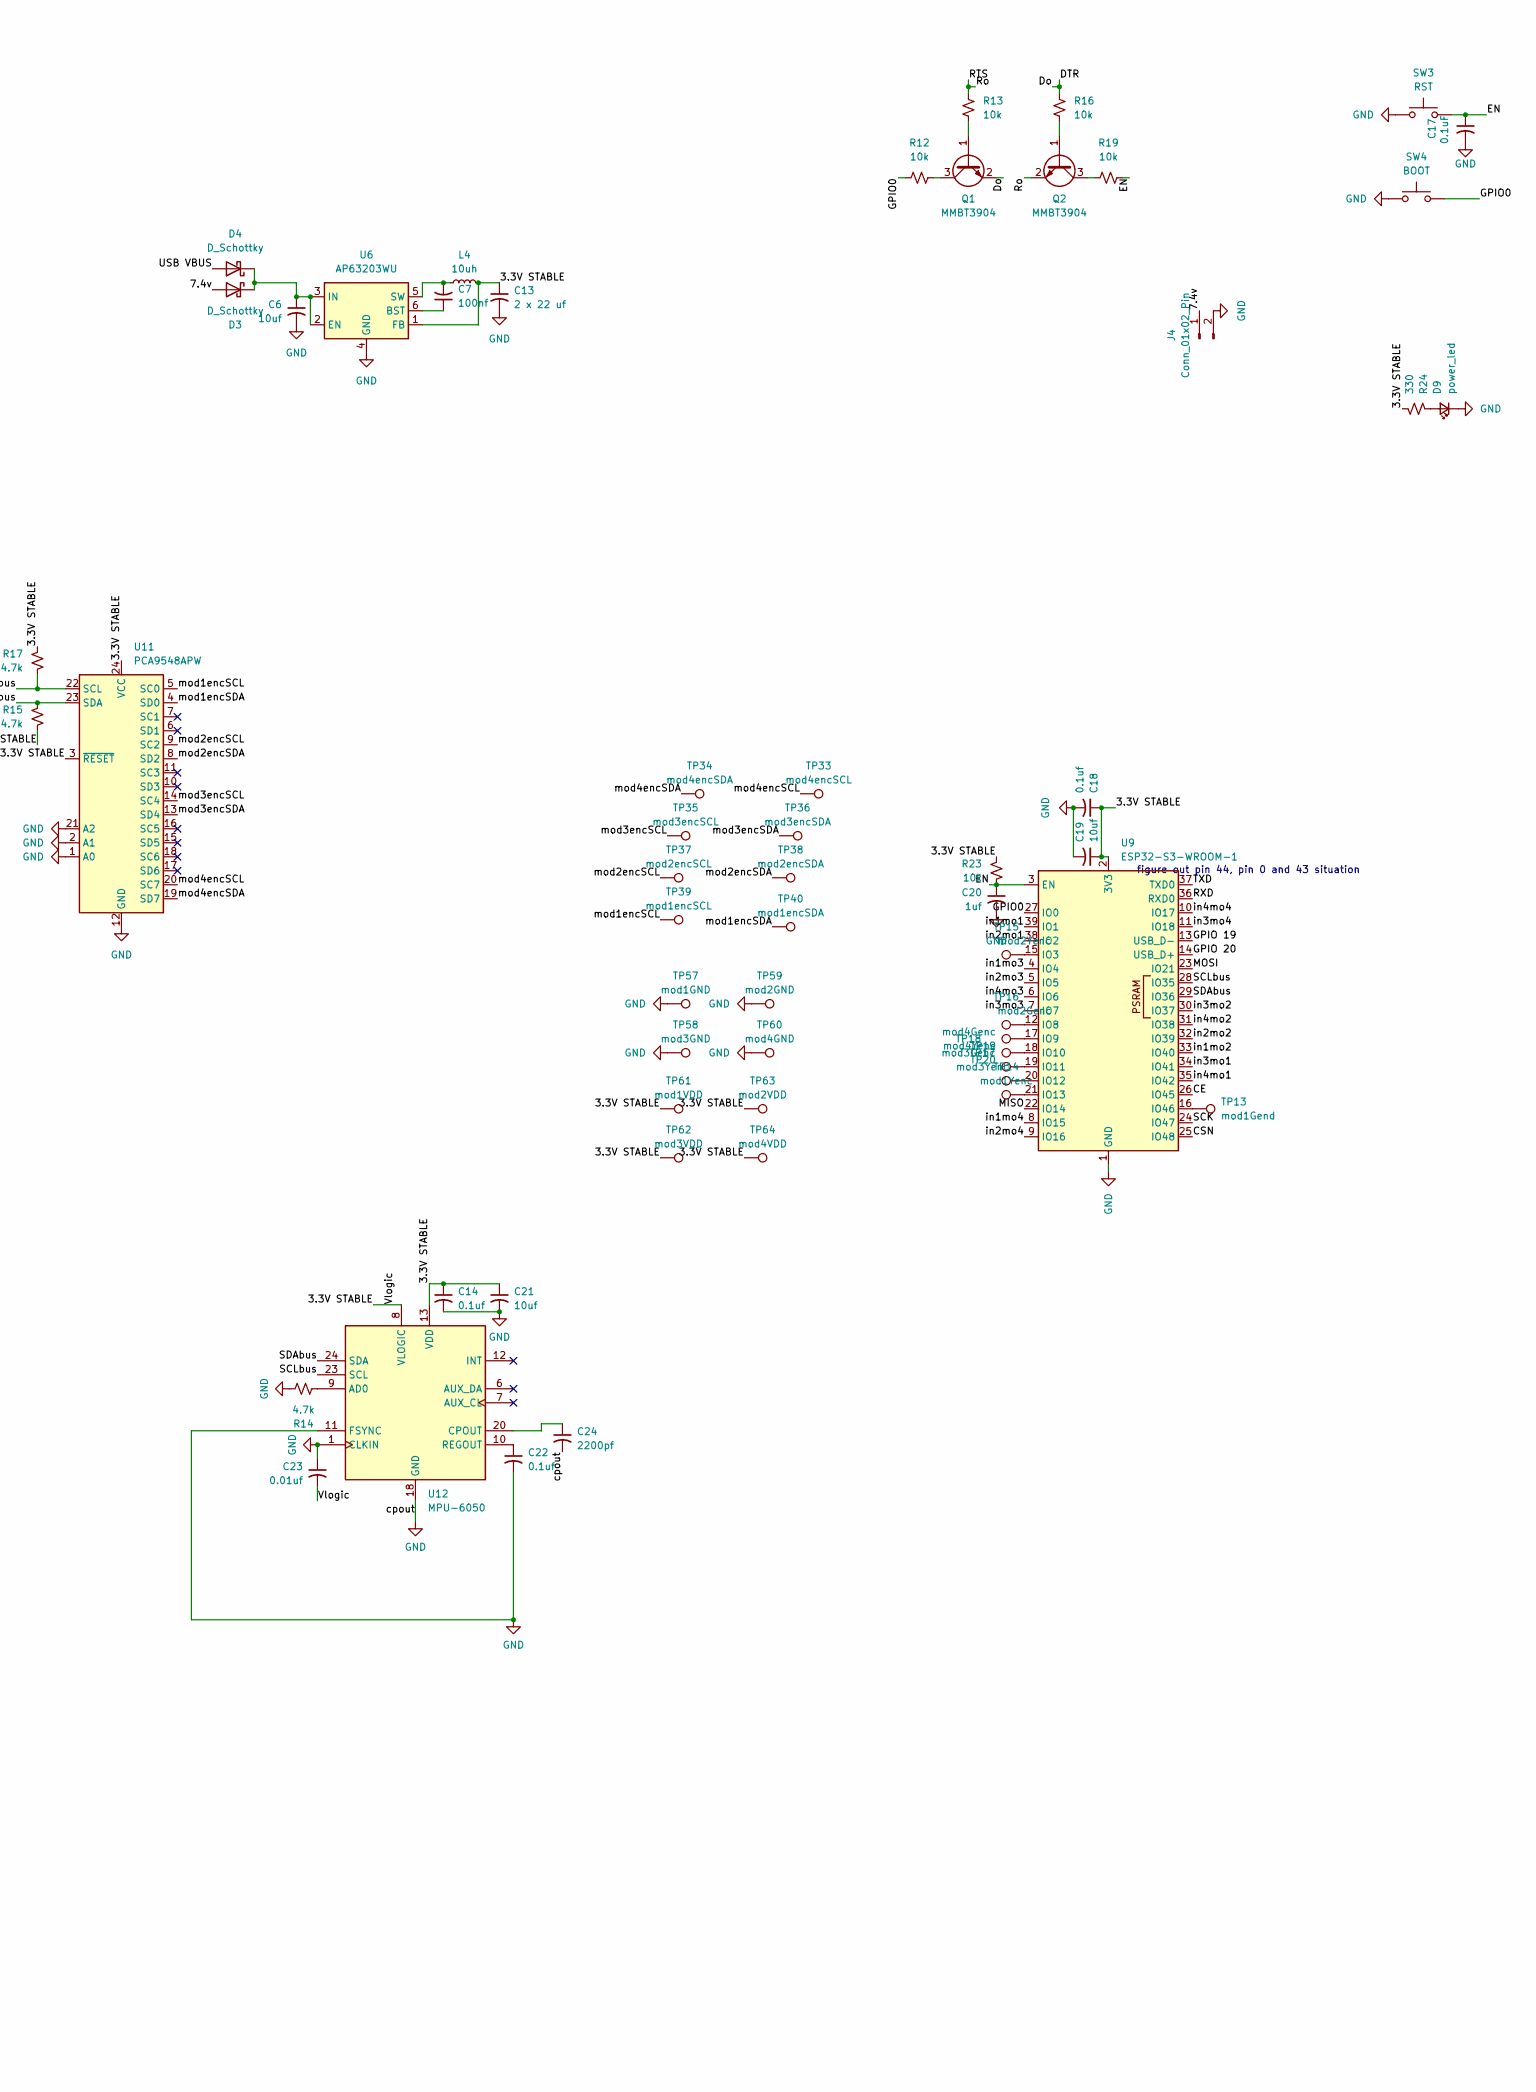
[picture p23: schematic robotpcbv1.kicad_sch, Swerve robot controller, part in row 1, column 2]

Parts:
C1: 33nf; C_0402_1005Metric
C2: 10nf; C_0402_1005Metric
C3: 1nf; C_0402_1005Metric
C4: 2.2nf; C_0402_1005Metric
C5: 4.7pf; C_0402_1005Metric
C6, C19, C21: 10uf; C_1206_3216Metric
C7: 100nf; C_0402_1005Metric
C8, C9: 22pf; C_0402_1005Metric
C10: 4.7uf; C_1206_3216Metric
C11, C14, C18, C22: 0.1uf; C_0603_1608Metric
C12: 0.1nf; C_0603_1608Metric
C13: 2 x 22 uf; C_0805_2012Metric
C15: 1.5pF; C_0402_1005Metric
C16: 1pF; C_0402_1005Metric
C17: 0.1uF; C_0603_1608Metric
C20: 1uf; C_1206_3216Metric
C23, C31, C34, C37, C40: 0.01uf; C_0402_1005Metric
C24: 2200pf; C_0402_1005Metric
C29, C32, C35, C38: 2.2uf; C_0603_1608Metric
C30, C33, C36, C39: 10uf; C_0805_2012Metric
D1, D2, D3, D4: D_Schottky; D_SOD-123
D9: power_led; LED_0603_1608Metric
J1, J2: USB_C_Receptacle_USB2.0_16P; USB_C_Receptacle_HRO_TYPE-C-31-M-12
J3: Conn_Coaxial_Small; SMA_Amphenol_901-144_Vertical
J4: Conn_01x02_Pin; AMASS_XT60-M_1x02_P7.20mm_Vertical
L1: 8.2nH; L_0402_1005Metric
L2: 2.7nh; L_0402_1005Metric
L3: 3.9nh; L_0402_1005Metric
L4: 10uh; WE-LQSA_5040
Q1, Q2: MMBT3904; SOT-23
R1: 22k; R_0603_1608Metric
R2, R3, R9, R10: 5.1k; R_0603_1608Metric
R4: 1m; R_0603_1608Metric
R5: 22.1k; R_0603_1608Metric
R6: 47.5k; R_0603_1608Metric
R7, R8: 1k; R_0603_1608Metric
R11, R12, R13, R16, R19, R23: 10k; R_0603_1608Metric
R14, R15, R17: 4.7k; R_0603_1608Metric
R24: 330; R_0603_1608Metric
SW3: RST; SW_Push_SPST_NO_Alps_SKRK
SW4: BOOT; SW_Push_SPST_NO_Alps_SKRK
TP5: out1mo4; TestPoint_Pad_D1.0mm
TP6: out2mo4; TestPoint_Pad_D1.0mm
TP7: out3mo4; TestPoint_Pad_D1.0mm
TP8: out4mo4; TestPoint_Pad_D1.0mm
TP9: out1mo1; TestPoint_Pad_D1.0mm
TP10: out2mo1; TestPoint_Pad_D1.0mm
TP11: out3mo1; TestPoint_Pad_D1.0mm
TP12: out4mo1; TestPoint_Pad_D1.0mm
TP13: mod1Gend; TestPoint_Pad_D1.0mm
TP14: mod1Yenc; TestPoint_Pad_D1.0mm
TP15: mod2Yenc; TestPoint_Pad_D1.0mm
TP16: mod2Genc; TestPoint_Pad_D1.0mm
TP17: mod3Yenc; TestPoint_Pad_D1.0mm
TP18: mod3Genc; TestPoint_Pad_D1.0mm
TP19: mod4Genc; TestPoint_Pad_D1.0mm
TP20: mod4Yenc; TestPoint_Pad_D1.0mm
TP21: out1mo2; TestPoint_Pad_D1.0mm
TP22: out2mo2; TestPoint_Pad_D1.0mm
TP23: out3mo2; TestPoint_Pad_D1.0mm
TP24: out4mo2; TestPoint_Pad_D1.0mm
TP29: out1mo3; TestPoint_Pad_D1.0mm
TP30: out2mo3; TestPoint_Pad_D1.0mm
TP31: out3mo3; TestPoint_Pad_D1.0mm
TP32: out4mo3; TestPoint_Pad_D1.0mm
TP33: mod4encSCL; TestPoint_Pad_D1.0mm
TP34: mod4encSDA; TestPoint_Pad_D1.0mm
TP35: mod3encSCL; TestPoint_Pad_D1.0mm
TP36: mod3encSDA; TestPoint_Pad_D1.0mm
TP37: mod2encSCL; TestPoint_Pad_D1.0mm
TP38: mod2encSDA; TestPoint_Pad_D1.0mm
TP39: mod1encSCL; TestPoint_Pad_D1.0mm
TP40: mod1encSDA; TestPoint_Pad_D1.0mm
TP57: mod1GND; TestPoint_Pad_D1.0mm
TP58: mod3GND; TestPoint_Pad_D1.0mm
TP59: mod2GND; TestPoint_Pad_D1.0mm
TP60: mod4GND; TestPoint_Pad_D1.0mm
TP61: mod1VDD; TestPoint_Pad_D1.0mm
TP62: mod3VDD; TestPoint_Pad_D1.0mm
TP63: mod2VDD; TestPoint_Pad_D1.0mm
TP64: mod4VDD; TestPoint_Pad_D1.0mm
U1: nRF24L01P; QFN-20-1EP_4x4mm_P0.5mm_EP2.5x2.5mm
U4: CP2102N-Axx-xQFN24; QFN-24-1EP_4x4mm_P0.5mm_EP2.6x2.6mm
U5: RFX2401C; QFN50P300X300X60-17N; DigiKey_Part_Number 863-1828-1-ND
U6: AP63203WU; TSOT-23-6
U8, U10, U13, U14: DRV8833PWP; HTSSOP-16-1EP_4.4x5mm_P0.65mm_EP3.4x5mm_Mask2.46x2.31mm_The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
U9: ESP32-S3-WROOM-1; ESP32-S3-WROOM-1U
U11: PCA9548APW; TSSOP-24_4.4x7.8mm_P0.65mm
U12: MPU-6050; InvenSense_QFN-24_4x4mm_P0.5mm
X1: 16mhz; Crystal_SMD_3225-4Pin_3.2x2.5mm

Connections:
/7.4v: C30.1, C31.1, C33.1, C34.1, C36.1, C37.1, C39.1, C40.1, D3.2 (A), J4.1, U8.12 (VM), U10.12 (VM), U13.12 (VM), U14.12 (VM)
/CE: R7.2, U1.1 (CE), U9.26 (IO45)
/CSN: U1.2 (CSN), U9.25 (IO48)
/DATA+: J1.A6 (D+), J1.B6 (D+), U4.3 (D+)
/DATA-: J1.A7 (D-), J1.B7 (D-), U4.4 (D-)
/DTR: Q1.2 (E), R16.1, U4.23 (~DTR)
/EN: C17.1, C20.1, R19.1, R23.1, SW3.2, U9.3 (EN)
/GPIO0: R12.2, SW4.2, U9.27 (IO0)
/GPIO 19: J2.A7 (D-), J2.B7 (D-), U9.13 (USB_D-)
/GPIO 20: J2.A6 (D+), J2.B6 (D+), U9.14 (USB_D+)
/MISO: U1.5 (MISO), U9.22 (IO14)
/MOSI: U1.4 (MOSI), U9.23 (IO21)
/RTS: Q2.2 (E), R13.1, U4.19 (~RTS)
/RXD: U4.20 (RXD), U9.36 (RXD0)
/SCK: U1.3 (SCK), U9.24 (IO47)
/SCLbus: R17.2, U9.28 (IO35), U11.22 (SCL), U12.23 (SCL)
/SDAbus: R15.1, U9.29 (IO36), U11.23 (SDA), U12.24 (SDA)
/TXD: U4.21 (TXD), U9.37 (TXD0)
/USB VBUS: C10.1, C11.1, D1.1 (K), D2.1 (K), D4.2 (A), R5.1
/VCP1: C31.2, U8.11 (VCP)
/VCP2: C34.2, U10.11 (VCP)
/VCP3: C37.2, U13.11 (VCP)
/VCP4: C40.2, U14.11 (VCP)
/VDD_PA: C4.1, C5.1, L2.2, U1.11 (VDD_PA), U5.5 (TXEN)
/in1mo1: U8.16 (AIN1), U9.39 (IO1)
/in1mo2: U9.33 (IO40), U10.16 (AIN1)
/in1mo3: U9.4 (IO4), U13.16 (AIN1)
/in1mo4: U9.8 (IO15), U14.16 (AIN1)
/in2mo1: U8.15 (AIN2), U9.38 (IO2)
/in2mo2: U9.32 (IO39), U10.15 (AIN2)
/in2mo3: U9.5 (IO5), U13.15 (AIN2)
/in2mo4: U9.9 (IO16), U14.15 (AIN2)
/in3mo1: U8.9 (BIN1), U9.34 (IO41)
/in3mo2: U9.30 (IO37), U10.9 (BIN1)
/in3mo3: U9.7 (IO7), U13.9 (BIN1)
/in3mo4: U9.11 (IO18), U14.9 (BIN1)
/in4mo1: U8.10 (BIN2), U9.35 (IO42)
/in4mo2: U9.31 (IO38), U10.10 (BIN2)
/in4mo3: U9.6 (IO6), U13.10 (BIN2)
/in4mo4: U9.10 (IO17), U14.10 (BIN2)
/mod1encSCL: TP39.1 (1_1), U11.5 (SC0)
/mod1encSDA: TP40.1 (1_1), U11.4 (SD0)
/mod2encSCL: TP37.1 (1_1), U11.9 (SC2)
/mod2encSDA: TP38.1 (1_1), U11.8 (SD2)
/mod3encSCL: TP35.1 (1_1), U11.14 (SC4)
/mod3encSDA: TP36.1 (1_1), U11.13 (SD4)
/mod4encSCL: TP33.1 (1_1), U11.20 (SC7)
/mod4encSDA: TP34.1 (1_1), U11.19 (SD7)
/out1mo1: TP9.1 (1_1), U8.2 (AOUT1)
/out1mo2: TP21.1 (1_1), U10.2 (AOUT1)
/out1mo3: TP29.1 (1_1), U13.2 (AOUT1)
/out1mo4: TP5.1 (1_1), U14.2 (AOUT1)
/out2mo1: TP10.1 (1_1), U8.4 (AOUT2)
/out2mo2: TP22.1 (1_1), U10.4 (AOUT2)
/out2mo3: TP30.1 (1_1), U13.4 (AOUT2)
/out2mo4: TP6.1 (1_1), U14.4 (AOUT2)
/out3mo1: TP11.1 (1_1), U8.7 (BOUT1)
/out3mo2: TP23.1 (1_1), U10.7 (BOUT1)
/out3mo3: TP31.1 (1_1), U13.7 (BOUT1)
/out3mo4: TP7.1 (1_1), U14.7 (BOUT1)
/out4mo1: TP12.1 (1_1), U8.5 (BOUT2)
/out4mo2: TP24.1 (1_1), U10.5 (BOUT2)
/out4mo3: TP32.1 (1_1), U13.5 (BOUT2)
/out4mo4: TP8.1 (1_1), U14.5 (BOUT2)
GND: C1.2, C2.2, C3.2, C4.2, C5.2, C6.2, C8.2, C9.2, C12.2, C13.2, C14.2, C16.2, C17.2, C18.2, C19.2, C20.2, C21.2, C22.2, C23.1, C24.2, C29.2, C30.2, C32.2, C33.2, C35.2, C36.2, C38.2, C39.2, D9.1 (K), J1.A1 (GND), J1.A12 (GND), J1.B1 (GND), J1.B12 (GND), J1.SH (SHIELD), J2.A1 (GND), J2.A12 (GND), J2.B1 (GND), J2.B12 (GND), J2.SH (SHIELD), J3.2 (Ext), J4.2, R1.2, R2.1, R3.1, R6.2, R9.1, R10.1, R11.2, R14.2, SW3.1, SW4.1, TP57.1 (1_1), TP58.1 (1_1), TP59.1 (1_1), TP60.1 (1_1), U1.8 (VSS), U1.14 (VSS), U1.17 (VSS), U1.20 (VSS), U1.21 (EPAD), U4.2 (GND), U4.25 (GND), U5.2 (GND), U5.3 (GND), U5.8 (GND), U5.9 (GND), U5.11 (GND), U5.17 (GND), U6.4 (GND), U8.3 (AISEN), U8.6 (BISEN), U8.13 (GND), U8.17 (GND), U9.1 (GND), U9.40 (GND), U9.41 (GND), U10.3 (AISEN), U10.6 (BISEN), U10.13 (GND), U10.17 (GND), U11.1 (A0), U11.2 (A1), U11.12 (GND), U11.21 (A2), U12.1 (CLKIN), U12.11 (FSYNC), U12.18 (GND), U13.3 (AISEN), U13.6 (BISEN), U13.13 (GND), U13.17 (GND), U14.3 (AISEN), U14.6 (BISEN), U14.13 (GND), U14.17 (GND), X1.2 (G), X1.4 (G)
unnamed: C15.1, L3.1
unnamed: D1.2 (A), J1.A4 (VBUS), J1.A9 (VBUS), J1.B4 (VBUS), J1.B9 (VBUS)
unnamed: D2.2 (A), J2.A4 (VBUS), J2.A9 (VBUS), J2.B4 (VBUS), J2.B9 (VBUS)
unnamed: C6.1, D3.1 (K), D4.1 (K), U6.2 (EN), U6.3 (IN)
unnamed: D9.2 (A), R24.1
unnamed: J1.A5 (CC1), R3.2
unnamed: J1.B5 (CC2), R2.2
unnamed: J2.A5 (CC1), R9.2
unnamed: J2.B5 (CC2), R10.2
unnamed: J3.1 (In), U5.10 (ANT)
unnamed: Q1.1 (B), R13.2
unnamed: Q1.3 (C), R12.1
unnamed: Q2.1 (B), R16.2
unnamed: Q2.3 (C), R19.2
unnamed: L1.1, L2.1, U1.12 (ANT1)
unnamed: L1.2, L3.2, U1.13 (ANT2)
unnamed: C1.1, U1.19 (DVDD)
unnamed: R1.1, U1.16 (IREF)
unnamed: C8.1, R4.1, U1.10 (XC1), X1.3
unnamed: C9.1, R4.2, U1.9 (XC2), X1.1
unnamed: R11.1, U4.17 (SUSPEND)
unnamed: R5.2, R6.1, U4.8 (VBUS)
unnamed: C10.2, C11.2, U4.7 (VREGIN)
unnamed: R8.2, U4.9 (~RST)
unnamed: R7.1, U5.6 (RXEN)
unnamed: C15.2, C16.1, U5.4 (TXRX)
unnamed: C7.1, U6.6 (BST)
unnamed: C7.2, L4.1, U6.5 (SW)
unnamed: C29.1, U8.14 (VINT)
unnamed: TP15.1 (1_1), U9.15 (IO3)
unnamed: TP16.1 (1_1), U9.12 (IO8)
unnamed: TP19.1 (1_1), U9.17 (IO9)
unnamed: TP20.1 (1_1), U9.18 (IO10)
unnamed: TP18.1 (1_1), U9.19 (IO11)
unnamed: TP17.1 (1_1), U9.20 (IO12)
unnamed: TP14.1 (1_1), U9.21 (IO13)
unnamed: TP13.1 (1_1), U9.16 (IO46)
unnamed: C32.1, U10.14 (VINT)
unnamed: R14.1, U12.9 (AD0)
unnamed: C24.1, U12.20 (CPOUT)
unnamed: C22.1, U12.10 (REGOUT)
unnamed: C35.1, U13.14 (VINT)
unnamed: C38.1, U14.14 (VINT)
VDD: C2.1, C3.1, C12.1, C13.1, C14.1, C18.1, C19.1, C21.1, C23.2, L4.2, R8.1, R15.2, R17.1, R23.2, R24.2, TP61.1 (1_1), TP62.1 (1_1), TP63.1 (1_1), TP64.1 (1_1), U1.7 (VDD), U1.15 (VDD), U1.18 (VDD), U4.5 (VIO), U4.6 (VDD), U5.14 (VDD), U5.16 (VDD), U6.1 (FB), U8.1 (~SLEEP), U9.2 (3V3), U10.1 (~SLEEP), U11.3 (~RESET), U11.24 (VCC), U12.8 (VLOGIC), U12.13 (VDD), U13.1 (~SLEEP), U14.1 (~SLEEP)

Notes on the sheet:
figure out pin 44, pin 0 and 43 situation
all non chip components that go to this chip use the 0402 package, vital to RF performance

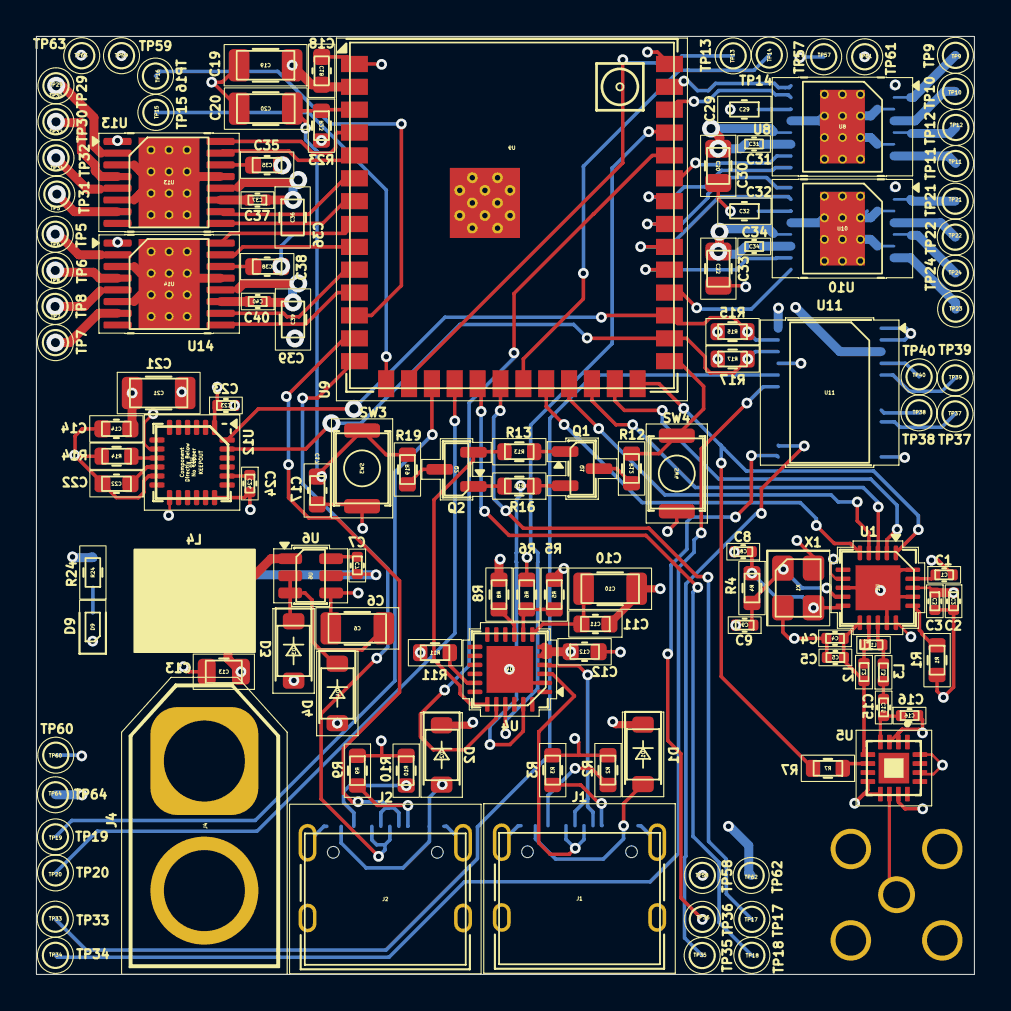
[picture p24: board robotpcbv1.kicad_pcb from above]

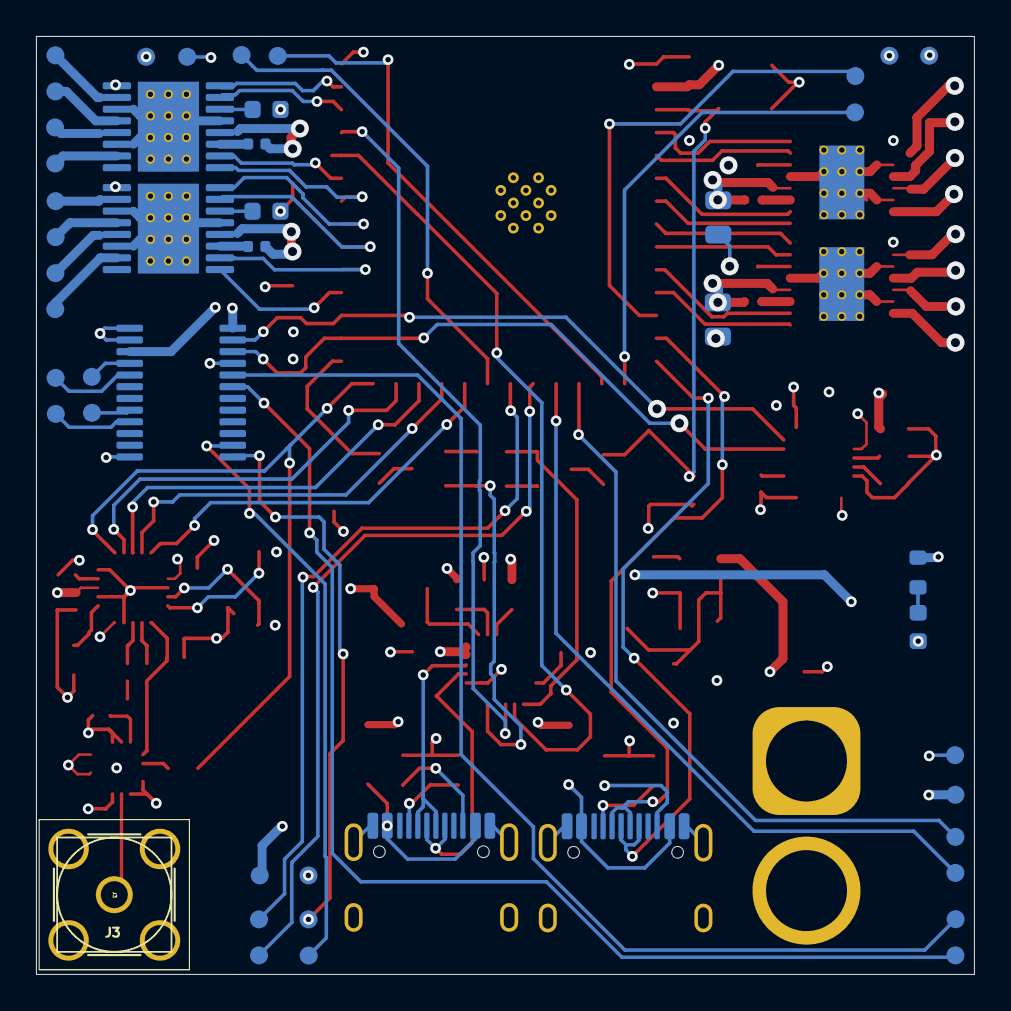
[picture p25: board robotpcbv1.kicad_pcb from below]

Board: 4 copper layers, 52.1 x 52.1 mm, 125 parts (54 on the bottom side), 109 nets.

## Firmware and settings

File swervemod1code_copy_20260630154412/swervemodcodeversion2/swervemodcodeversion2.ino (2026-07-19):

#include <Arduino.h>
#include <Wire.h>
#include <SPI.h>

// Standard non-clashing I2C hardware pin mappings
#define MPUscl 3
#define MPUsda 17
#define PLEXsda 12
#define PLEXscl 11

// Encoder Pins
#define mod1_Genc 41
#define mod1_Yenc 42
#define mod2_Genc 2
#define mod2_Yenc 1
#define mod3_Genc 14
#define mod3_Yenc 13
#define mod4_Genc 36
#define mod4_Yenc 35

// Motor Driver Pins
#define mod1_DRIVE_IN4 37
#define mod1_DRIVE_IN3 38
#define mod1_STEER_IN2 39
#define mod1_STEER_IN1 40

#define mod2_DRIVE_IN4 43
#define mod2_DRIVE_IN3 21
#define mod2_STEER_IN2 4
#define mod2_STEER_IN1 5

#define mod3_DRIVE_IN4 6
#define mod3_DRIVE_IN3 7
#define mod3_STEER_IN2 37
#define mod3_STEER_IN1 48

#define mod4_DRIVE_IN4 0
#define mod4_DRIVE_IN3 45
#define mod4_STEER_IN2 8
#define mod4_STEER_IN1 18

// Raw Register Command Sets
#define R_REGISTER 0x00
#define W_REGISTER 0x20
#define R_RX_PAYLOAD 0x61
#define FLUSH_RX 0xE2

// nRF24L01 Memory Addresses
#define STATUS_REG 0x07
#define CONFIG_REG 0x00
#define RF_SETUP_REG 0x06
#define EN_AA_REG 0x01
#define FIFO_STATUS_REG 0x17
#define RX_ADDR_P0_REG 0x0A
#define RX_PW_P0_REG 0x11

double prevAngENC1 = 0, prevAngENC2 = 0, prevAngENC3 = 0, prevAngENC4 = 0;
double DriveComp1 = 0, DriveComp2 = 0, DriveComp3 = 0, DriveComp4 = 0;
unsigned long lastCompTime = 0;

// Hardware SPI Pins (Official hardware-optimized ESP32-S3 pins)
const int CE_PIN = 44;
const int CSN_PIN = 10;
const int SCK_PIN = 15;
const int MOSI_PIN = 16;
const int MISO_PIN = 9;

// Volatile Encoder Counters
volatile long Mod1 = 0;
volatile long Mod2 = 0;
volatile long Mod3 = 0;
volatile long Mod4 = 0;

volatile long Ticks1 = 0;
volatile long Ticks2 = 0;
volatile long Ticks3 = 0;
volatile long Ticks4 = 0;

// Telemetry & Control Floats
float RawDriveX = 2048;
float RawDriveY = 2048;
float RawSteerX = 2048;
float RawSteerY = 2048;
float GYx = 0;
float GYy = 0;
float GYz = 0;
float angENC1 = 0;
float angENC2 = 0;
float angENC3 = 0;
float angENC4 = 0;

unsigned long sensortime = 0;
unsigned long printtime = 0;

// Motor State History Counters
int driveIN3_lastMod1 = 0; int driveIN4_lastMod1 = 0; int steerIN1_lastMod1 = 0; int steerIN2_lastMod1 = 0;
int driveIN3_lastMod2 = 0; int driveIN4_lastMod2 = 0; int steerIN1_lastMod2 = 0; int steerIN2_lastMod2 = 0;
int driveIN3_lastMod3 = 0; int driveIN4_lastMod3 = 0; int steerIN1_lastMod3 = 0; int steerIN2_lastMod3 = 0;
int driveIN3_lastMod4 = 0; int driveIN4_lastMod4 = 0; int steerIN1_lastMod4 = 0; int steerIN2_lastMod4 = 0;

float Isum[5] = {0, 0, 0, 0, 0};
float lastERR[5] = {0, 0, 0, 0, 0};

float P1, I1, D1, P2, I2, D2, P3, I3, D3, P4, I4, D4;

float minERR1 = 999, maxERR1 = -999;// TEMPOWARY
float minERR2 = 999, maxERR2 = -999;
float minERR3 = 999, maxERR3 = -999;
float minERR4 = 999, maxERR4 = -999;
unsigned long oscTime = 0;

double kp1 = 1.5;
double ki1 = 0.05;
double kd1 = 0.4;

double kp2 = 1.5;
double ki2 = 0.05;
double kd2 = 0.4;

double kp3 = 1.5;
double ki3 = 0.05;
double kd3 = 0.4;

double kp4 = 1.5;
double ki4 = 0.05;
double kd4 = 0.4;

// FIX #4: OUT1-4 now declared here, and these are the ONLY output variables
// PID() writes to these, and STEERmo() reads these -- names now match.
double OUT1 = 0;
double OUT2 = 0;
double OUT3 = 0;
double OUT4 = 0;

int Disp1X = -54;
int Disp1Y = 54;
int Disp2X = -54;
int Disp2Y = -54;
int Disp3X = 54;
int Disp3Y = 54;
int Disp4X = 54;
int Disp4Y = -54;

double TargSPEED1 = 0;
double TargSPEED2 = 0;
double TargSPEED3 = 0;
double TargSPEED4 = 0;

double TargANG1 = 0;
double TargANG2 = 0;
double TargANG3 = 0;
double TargANG4 = 0;

double ERR1 = 0;
double ERR2 = 0;
double ERR3 = 0;
double ERR4 = 0;

struct telemetry {
  float DjoyX;
  float DjoyY;
  float SjoyX;
  float SjoyY;
};
telemetry joystickdata;


// --- INTERRUPT SERVICE ROUTINES (ISRs) ---

void IRAM_ATTR INTERmod1() {
  if (digitalRead(mod1_Genc) == LOW) Mod1++; else Mod1--;
}

void IRAM_ATTR INTERmod2() {
  if (digitalRead(mod2_Genc) == LOW) Mod2++; else Mod2--;
}

void IRAM_ATTR INTERmod3() {
  if (digitalRead(mod3_Genc) == LOW) Mod3++; else Mod3--;
}

void IRAM_ATTR INTERmod4() {
  if (digitalRead(mod4_Genc) == LOW) Mod4++; else Mod4--;
}
void CompensateDrive(int module) {
  double deltaTime = (millis() - lastCompTime) / 1000.0;   // seconds since last loop
  if (deltaTime <= 0) deltaTime = 0.001;  // guard against divide-by-zero on the very first call

  double currentAng, prevAng, targSpeed;
  switch (module) {
    case 1: currentAng = angENC1; prevAng = prevAngENC1; targSpeed = TargSPEED1; break;
    case 2: currentAng = angENC2; prevAng = prevAngENC2; targSpeed = TargSPEED2; break;
    case 3: currentAng = angENC3; prevAng = prevAngENC3; targSpeed = TargSPEED3; break;
    case 4: currentAng = angENC4; prevAng = prevAngENC4; targSpeed = TargSPEED4; break;
    default: return;
  }

  double deltaAngle = currentAng - prevAng;
  if (deltaAngle > 180) deltaAngle -= 360;      // wraparound-safe, same idea as ERR()
  if (deltaAngle < -180) deltaAngle += 360;

  double steerHousingSpeed = deltaAngle / deltaTime;   // deg/sec
  double compensated = (targSpeed - 0.389 * steerHousingSpeed) / 0.611;
  compensated = constrain(compensated, -4095, 4095);

  switch (module) {
    case 1: DriveComp1 = compensated; prevAngENC1 = currentAng; break;
    case 2: DriveComp2 = compensated; prevAngENC2 = currentAng; break;
    case 3: DriveComp3 = compensated; prevAngENC3 = currentAng; break;
    case 4: DriveComp4 = compensated; prevAngENC4 = currentAng; break;
  }
}

// --- HARDWARE SENSOR INTEGRATIONS ---

void MPUfetchGY() {
  Wire.beginTransmission(0x68);
  Wire.write(0x43);
  Wire.endTransmission(false);
  if (Wire.requestFrom(0x68, 6) == 6) {
    uint8_t xHI = Wire.read(); uint8_t xLO = Wire.read();
    uint8_t yHI = Wire.read(); uint8_t yLO = Wire.read();
    uint8_t zHI = Wire.read(); uint8_t zLO = Wire.read();

    int rawX = (xHI << 8) | xLO;
    int rawY = (yHI << 8) | yLO;
    int rawZ = (zHI << 8) | zLO;

    GYx = rawX / 131.0;
    GYy = rawY / 131.0;
    GYz = rawZ / 131.0;
  }
}

float PLEXfetch(int module) {
  int channelMap[5] = {0, 7, 6, 5, 2};  // module 2 currently on channel 6 (see conversation history)
  int channel = channelMap[module];

  delayMicroseconds(10);
  if (module >= 1 && module <= 4) {
    Wire1.beginTransmission(0x70);
    Wire1.write(1 << channel);
    Wire1.endTransmission();
    delay(2);

    Wire1.beginTransmission(0x36);
    Wire1.write(0x0E);
    Wire1.endTransmission(false);

    if (Wire1.requestFrom(0x36, 2) == 2) {
      uint8_t angHI = Wire1.read();
      uint8_t angLO = Wire1.read();
      int rawANG = (angHI << 8) | angLO;
      float ANG = (rawANG * 360.0) / 4096.0;
      return ANG;
    }
  }
  return 0;
}

void MCUwake() {
  Wire.beginTransmission(0x68);
  Wire.write(0x6B);
  Wire.write(0x00);
  Wire.endTransmission();
}


// --- MOTOR DRIVE CONTROLLERS ---

void DRIVEmo(int modNumD) {
  if (modNumD == 1) {
    if (DriveComp1  > 0) {
      ledcDetach(mod1_DRIVE_IN4);
      pinMode(mod1_DRIVE_IN4, OUTPUT); digitalWrite(mod1_DRIVE_IN4, LOW);
      analogWrite(mod1_DRIVE_IN3, (int)DriveComp1);
      driveIN3_lastMod1 = (int)DriveComp1; driveIN4_lastMod1 = 0;
    } else if (DriveComp1  < 0) {
      ledcDetach(mod1_DRIVE_IN3);
      pinMode(mod1_DRIVE_IN3, OUTPUT); digitalWrite(mod1_DRIVE_IN3, LOW);
      analogWrite(mod1_DRIVE_IN4, (int)(-DriveComp1 ));
      driveIN3_lastMod1 = 0; driveIN4_lastMod1 = (int)(-DriveComp1);
    } else if(DriveComp1 == 0){
      ledcDetach(mod1_DRIVE_IN3);
      ledcDetach(mod1_DRIVE_IN4);
      pinMode(mod1_DRIVE_IN3, OUTPUT); digitalWrite(mod1_DRIVE_IN3, LOW);
      pinMode(mod1_DRIVE_IN4, OUTPUT); digitalWrite(mod1_DRIVE_IN4, LOW);
      driveIN3_lastMod1 = 0; driveIN4_lastMod1 = 0;
    }
  } 
  else if (modNumD == 2){ 
      if (DriveComp2 > 0) {
      ledcDetach(mod2_DRIVE_IN4);
      pinMode(mod2_DRIVE_IN4, OUTPUT); digitalWrite(mod2_DRIVE_IN4, LOW);
      analogWrite(mod2_DRIVE_IN3, (int)DriveComp2);
      driveIN3_lastMod2 = (int)DriveComp2; driveIN4_lastMod2 = 0;
    } else if (DriveComp2 < 0) {
      ledcDetach(mod2_DRIVE_IN3);
      pinMode(mod2_DRIVE_IN3, OUTPUT); digitalWrite(mod2_DRIVE_IN3, LOW);
      analogWrite(mod2_DRIVE_IN4, (int)(-DriveComp2));
      driveIN3_lastMod2 = 0; driveIN4_lastMod2 = (int)(-DriveComp2);
    } else if(DriveComp2 == 0) {
      ledcDetach(mod2_DRIVE_IN3);
      ledcDetach(mod2_DRIVE_IN4);
      pinMode(mod2_DRIVE_IN3, OUTPUT); digitalWrite(mod2_DRIVE_IN3, LOW);
      pinMode(mod2_DRIVE_IN4, OUTPUT); digitalWrite(mod2_DRIVE_IN4, LOW);
      driveIN3_lastMod2 = 0; driveIN4_lastMod2 = 0;
    }
  }
  else if (modNumD == 3) {
    if (DriveComp3 > 0) {
      ledcDetach(mod3_DRIVE_IN4);
      pinMode(mod3_DRIVE_IN4, OUTPUT); digitalWrite(mod3_DRIVE_IN4, LOW);
      analogWrite(mod3_DRIVE_IN3, (int)DriveComp3);
      driveIN3_lastMod3 = (int)DriveComp3; driveIN4_lastMod3 = 0;
    } else if (DriveComp3 < 0) {
      ledcDetach(mod3_DRIVE_IN3);
      pinMode(mod3_DRIVE_IN3, OUTPUT); digitalWrite(mod3_DRIVE_IN3, LOW);
      analogWrite(mod3_DRIVE_IN4, (int)(-DriveComp3));
      driveIN3_lastMod3 = 0; driveIN4_lastMod3 = (int)(-DriveComp3);
    } else if (DriveComp3 == 0) {
      ledcDetach(mod3_DRIVE_IN3);
      ledcDetach(mod3_DRIVE_IN4);
      pinMode(mod3_DRIVE_IN3, OUTPUT); digitalWrite(mod3_DRIVE_IN3, LOW);
      pinMode(mod3_DRIVE_IN4, OUTPUT); digitalWrite(mod3_DRIVE_IN4, LOW);
      driveIN3_lastMod3 = 0; driveIN4_lastMod3 = 0;
    }
  }
  else if (modNumD == 4) {
    if (DriveComp4 > 0) {
      ledcDetach(mod4_DRIVE_IN4);
      pinMode(mod4_DRIVE_IN4, OUTPUT); digitalWrite(mod4_DRIVE_IN4, LOW);
      analogWrite(mod4_DRIVE_IN3, (int)DriveComp4);
      driveIN3_lastMod4 = (int)DriveComp4; driveIN4_lastMod4 = 0;
    } else if (DriveComp4 < 0) {
      ledcDetach(mod4_DRIVE_IN3);
      pinMode(mod4_DRIVE_IN3, OUTPUT); digitalWrite(mod4_DRIVE_IN3, LOW);
      analogWrite(mod4_DRIVE_IN4, (int)(-DriveComp4));
      driveIN3_lastMod4 = 0; driveIN4_lastMod4 = (int)(-DriveComp4);
    } else if (DriveComp4 == 0) {
      ledcDetach(mod4_DRIVE_IN3);
      ledcDetach(mod4_DRIVE_IN4);
      pinMode(mod4_DRIVE_IN3, OUTPUT); digitalWrite(mod4_DRIVE_IN3, LOW);
      pinMode(mod4_DRIVE_IN4, OUTPUT); digitalWrite(mod4_DRIVE_IN4, LOW);
      driveIN3_lastMod4 = 0; driveIN4_lastMod4 = 0;
    }
  }
}


void STEERmo(int modNumS) {
  if (modNumS == 1) {
    if (OUT1 > 0) {
      ledcDetach(mod1_STEER_IN1);
      pinMode(mod1_STEER_IN1, OUTPUT); digitalWrite(mod1_STEER_IN1, LOW);
      analogWrite(mod1_STEER_IN2, (int)OUT1);
      steerIN1_lastMod1 = 0; steerIN2_lastMod1 = (int)OUT1;
    } else if (OUT1 < 0) {
      ledcDetach(mod1_STEER_IN2);
      pinMode(mod1_STEER_IN2, OUTPUT); digitalWrite(mod1_STEER_IN2, LOW);
      analogWrite(mod1_STEER_IN1, (int)(-OUT1));
      steerIN1_lastMod1 = (int)(-OUT1); steerIN2_lastMod1 = 0;
    } else {
      ledcDetach(mod1_STEER_IN1);
      ledcDetach(mod1_STEER_IN2);
      pinMode(mod1_STEER_IN1, OUTPUT); digitalWrite(mod1_STEER_IN1, LOW);
      pinMode(mod1_STEER_IN2, OUTPUT); digitalWrite(mod1_STEER_IN2, LOW);
      steerIN1_lastMod1 = 0; steerIN2_lastMod1 = 0;
    }
  }
  else if (modNumS == 2) {
    if (OUT2 > 0) {
      ledcDetach(mod2_STEER_IN1);
      pinMode(mod2_STEER_IN1, OUTPUT); digitalWrite(mod2_STEER_IN1, LOW);
      analogWrite(mod2_STEER_IN2, (int)OUT2);
      steerIN1_lastMod2 = 0; steerIN2_lastMod2 = (int)OUT2;
    } else if (OUT2 < 0) {
      ledcDetach(mod2_STEER_IN2);
      pinMode(mod2_STEER_IN2, OUTPUT); digitalWrite(mod2_STEER_IN2, LOW);
      analogWrite(mod2_STEER_IN1, (int)(-OUT2));
      steerIN1_lastMod2 = (int)(-OUT2); steerIN2_lastMod2 = 0;
    } else {
      ledcDetach(mod2_STEER_IN1);
      ledcDetach(mod2_STEER_IN2);
      pinMode(mod2_STEER_IN1, OUTPUT); digitalWrite(mod2_STEER_IN1, LOW);
      pinMode(mod2_STEER_IN2, OUTPUT); digitalWrite(mod2_STEER_IN2, LOW);
      steerIN1_lastMod2 = 0; steerIN2_lastMod2 = 0;
    }
  }
  else if (modNumS == 3) {
    if (OUT3 > 0) {
      ledcDetach(mod3_STEER_IN1);
      pinMode(mod3_STEER_IN1, OUTPUT); digitalWrite(mod3_STEER_IN1, LOW);
      analogWrite(mod3_STEER_IN2, (int)OUT3);
      steerIN1_lastMod3 = 0; steerIN2_lastMod3 = (int)OUT3;
    } else if (OUT3 < 0) {
      ledcDetach(mod3_STEER_IN2);
      pinMode(mod3_STEER_IN2, OUTPUT); digitalWrite(mod3_STEER_IN2, LOW);
      analogWrite(mod3_STEER_IN1, (int)(-OUT3));
      steerIN1_lastMod3 = (int)(-OUT3); steerIN2_lastMod3 = 0;
    } else {
      ledcDetach(mod3_STEER_IN1);
      ledcDetach(mod3_STEER_IN2);
      pinMode(mod3_STEER_IN1, OUTPUT); digitalWrite(mod3_STEER_IN1, LOW);
      pinMode(mod3_STEER_IN2, OUTPUT); digitalWrite(mod3_STEER_IN2, LOW);
      steerIN1_lastMod3 = 0; steerIN2_lastMod3 = 0;
    }
  }
  else if (modNumS == 4) {
    if (OUT4 > 0) {
      ledcDetach(mod4_STEER_IN1);
      pinMode(mod4_STEER_IN1, OUTPUT); digitalWrite(mod4_STEER_IN1, LOW);
      analogWrite(mod4_STEER_IN2, (int)OUT4);
      steerIN1_lastMod4 = 0; steerIN2_lastMod4 = (int)OUT4;
    } else if (OUT4 < 0) {
      ledcDetach(mod4_STEER_IN2);
      pinMode(mod4_STEER_IN2, OUTPUT); digitalWrite(mod4_STEER_IN2, LOW);
      analogWrite(mod4_STEER_IN1, (int)(-OUT4));
      steerIN1_lastMod4 = (int)(-OUT4); steerIN2_lastMod4 = 0;
    } else {
      ledcDetach(mod4_STEER_IN1);
      ledcDetach(mod4_STEER_IN2);
      pinMode(mod4_STEER_IN1, OUTPUT); digitalWrite(mod4_STEER_IN1, LOW);
      pinMode(mod4_STEER_IN2, OUTPUT); digitalWrite(mod4_STEER_IN2, LOW);
      steerIN1_lastMod4 = 0; steerIN2_lastMod4 = 0;
    }
  }
}


void writeRegister(uint8_t REG, uint8_t value) {
  digitalWrite(CSN_PIN, LOW);
  SPI.transfer(W_REGISTER | REG);
  SPI.transfer(value);
  digitalWrite(CSN_PIN, HIGH);
}

void writeCommand(uint8_t COM) {
  digitalWrite(CSN_PIN, LOW);
  SPI.transfer(COM);
  digitalWrite(CSN_PIN, HIGH);
}

void writeAddress(uint8_t REG, uint8_t* addr, int size) {
  digitalWrite(CSN_PIN, LOW);
  SPI.transfer(W_REGISTER | REG);
  for(int x=0; x<size; x++){
    SPI.transfer(addr[x]);
  }
  digitalWrite(CSN_PIN, HIGH);
}

uint8_t readRegister(uint8_t REG){
  digitalWrite(CSN_PIN, LOW);
  SPI.transfer(R_REGISTER | REG);
  uint8_t result = SPI.transfer(0x00);
  digitalWrite(CSN_PIN, HIGH);
  return result;
}

void printMotorState(int MODNUM){
  if (MODNUM == 1){
    Serial.println("MOTOR OUTPUT STATE MODULE 1:");
    Serial.print("  DRIVE_IN3: "); Serial.print(digitalRead(mod1_DRIVE_IN3) ? "HIGH" : "LOW");
    Serial.print("  (PWM last set: "); Serial.print(driveIN3_lastMod1); Serial.println(")");
    Serial.print("  DRIVE_IN4: "); Serial.print(digitalRead(mod1_DRIVE_IN4) ? "HIGH" : "LOW");
    Serial.print("  (PWM last set: "); Serial.print(driveIN4_lastMod1); Serial.println(")");
    Serial.print("  STEER_IN1: "); Serial.print(digitalRead(mod1_STEER_IN1) ? "HIGH" : "LOW");
    Serial.print("  (PWM last set: "); Serial.print(steerIN1_lastMod1); Serial.println(")");
    Serial.print("  STEER_IN2: "); Serial.print(digitalRead(mod1_STEER_IN2) ? "HIGH" : "LOW");
    Serial.print("  (PWM last set: "); Serial.print(steerIN2_lastMod1); Serial.println(")");
  } else if (MODNUM == 2){
    Serial.println("MOTOR OUTPUT STATE MODULE 2:");
    Serial.print("  DRIVE_IN3: "); Serial.print(digitalRead(mod2_DRIVE_IN3) ? "HIGH" : "LOW");
    Serial.print("  (PWM last set: "); Serial.print(driveIN3_lastMod2); Serial.println(")");
    Serial.print("  DRIVE_IN4: "); Serial.print(digitalRead(mod2_DRIVE_IN4) ? "HIGH" : "LOW");
    Serial.print("  (PWM last set: "); Serial.print(driveIN4_lastMod2); Serial.println(")");
    Serial.print("  STEER_IN1: "); Serial.print(digitalRead(mod2_STEER_IN1) ? "HIGH" : "LOW");
    Serial.print("  (PWM last set: "); Serial.print(steerIN1_lastMod2); Serial.println(")");
    Serial.print("  STEER_IN2: "); Serial.print(digitalRead(mod2_STEER_IN2) ? "HIGH" : "LOW");
    Serial.print("  (PWM last set: "); Serial.print(steerIN2_lastMod2); Serial.println(")");
  } else if (MODNUM == 3){
    Serial.println("MOTOR OUTPUT STATE MODULE 3:");
    Serial.print("  DRIVE_IN3: "); Serial.print(digitalRead(mod3_DRIVE_IN3) ? "HIGH" : "LOW");
    Serial.print("  (PWM last set: "); Serial.print(driveIN3_lastMod3); Serial.println(")");
    Serial.print("  DRIVE_IN4: "); Serial.print(digitalRead(mod3_DRIVE_IN4) ? "HIGH" : "LOW");
    Serial.print("  (PWM last set: "); Serial.print(driveIN4_lastMod3); Serial.println(")");
    Serial.print("  STEER_IN1: "); Serial.print(digitalRead(mod3_STEER_IN1) ? "HIGH" : "LOW");
    Serial.print("  (PWM last set: "); Serial.print(steerIN1_lastMod3); Serial.println(")");
    Serial.print("  STEER_IN2: "); Serial.print(digitalRead(mod3_STEER_IN2) ? "HIGH" : "LOW");
    Serial.print("  (PWM last set: "); Serial.print(steerIN2_lastMod3); Serial.println(")");
  } else if (MODNUM == 4){
    Serial.println("MOTOR OUTPUT STATE MODULE 4:");
    Serial.print("  DRIVE_IN3: "); Serial.print(digitalRead(mod4_DRIVE_IN3) ? "HIGH" : "LOW");
    Serial.print("  (PWM last set: "); Serial.print(driveIN3_lastMod4); Serial.println(")");
    Serial.print("  DRIVE_IN4: "); Serial.print(digitalRead(mod4_DRIVE_IN4) ? "HIGH" : "LOW");
    Serial.print("  (PWM last set: "); Serial.print(driveIN4_lastMod4); Serial.println(")");
    Serial.print("  STEER_IN1: "); Serial.print(digitalRead(mod4_STEER_IN1) ? "HIGH" : "LOW");
    Serial.print("  (PWM last set: "); Serial.print(steerIN1_lastMod4); Serial.println(")");
    Serial.print("  STEER_IN2: "); Serial.print(digitalRead(mod4_STEER_IN2) ? "HIGH" : "LOW");
    Serial.print("  (PWM last set: "); Serial.print(steerIN2_lastMod4); Serial.println(")");
  }
}
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
void loop() {

  noInterrupts();
  Ticks1 = Mod1;
  Ticks2 = Mod2;
  Ticks3 = Mod3;
  Ticks4 = Mod4;
  interrupts();

  uint8_t FIFO = readRegister(FIFO_STATUS_REG);
  if ((FIFO & 0x01) == 0){
    digitalWrite(CSN_PIN, LOW);
    SPI.transfer(R_RX_PAYLOAD);
    SPI.transferBytes(NULL, (uint8_t*)&joystickdata, sizeof(joystickdata));
    digitalWrite(CSN_PIN, HIGH);

    writeRegister(STATUS_REG, 0x70);
    writeCommand(FLUSH_RX);

    RawDriveX = joystickdata.DjoyX;
    RawDriveY = joystickdata.DjoyY;
    RawSteerX = joystickdata.SjoyX;
    RawSteerY = joystickdata.SjoyY;
  }

    angENC1 = PLEXfetch(1);
    angENC2 = PLEXfetch(2);
    angENC3 = PLEXfetch(3);
    angENC4 = PLEXfetch(4);

    VectorMath();
    PID(1); PID(2); PID(3); PID(4);

    //TEMP
if (ERR1 < minERR1) minERR1 = ERR1;
if (ERR1 > maxERR1) maxERR1 = ERR1;
if (ERR2 < minERR2) minERR2 = ERR2;
if (ERR2 > maxERR2) maxERR2 = ERR2;
if (ERR3 < minERR3) minERR3 = ERR3;
if (ERR3 > maxERR3) maxERR3 = ERR3;
if (ERR4 < minERR4) minERR4 = ERR4;
if (ERR4 > maxERR4) maxERR4 = ERR4;
//TEMP 

    CompensateDrive(1); CompensateDrive(2); CompensateDrive(3); CompensateDrive(4);
lastCompTime = millis();   // reset for next loop's deltaTime calculation

    DRIVEmo(1); STEERmo(1);
    DRIVEmo(2); STEERmo(2);
    DRIVEmo(3); STEERmo(3);
    DRIVEmo(4); STEERmo(4);

    //temp
    if (millis() - oscTime >= 2000) {   // report every 2 seconds
  oscTime = millis();
  Serial.print("OSC RANGE (deg)  M1:"); Serial.print(maxERR1 - minERR1, 1);
  Serial.print("  M2:"); Serial.print(maxERR2 - minERR2, 1);
  Serial.print("  M3:"); Serial.print(maxERR3 - minERR3, 1);
  Serial.print("  M4:"); Serial.println(maxERR4 - minERR4, 1);

  // reset for the next window
  minERR1 = maxERR1 = ERR1;
  minERR2 = maxERR2 = ERR2;
  minERR3 = maxERR3 = ERR3;
  minERR4 = maxERR4 = ERR4;
}
//temp

  if(millis() - sensortime >= 50) {
    sensortime = millis();
    MPUfetchGY();
  }

  if(millis() - printtime >= 250) {
    printtime = millis();
    Serial.print("RADIO:0x"); Serial.print(readRegister(STATUS_REG), HEX);
    Serial.print("  GYRO X:"); Serial.print(GYx, 1);
    Serial.print(" Y:"); Serial.print(GYy, 1);
    Serial.print(" Z:"); Serial.println(GYz, 1);

    Serial.print("ENC(deg)  M1:"); Serial.print(angENC1, 1);
    Serial.print("  M2:"); Serial.print(angENC2, 1);
    Serial.print("  M3:"); Serial.print(angENC3, 1);
    Serial.print("  M4:"); Serial.println(angENC4, 1);

    Serial.print("TARG ANG  M1:"); Serial.print(TargANG1, 1);
    Serial.print("  M2:"); Serial.print(TargANG2, 1);
    Serial.print("  M3:"); Serial.print(TargANG3, 1);
    Serial.print("  M4:"); Serial.println(TargANG4, 1);

    Serial.print("ERR  M1:"); Serial.print(ERR1, 1);
    Serial.print("  M2:"); Serial.print(ERR2, 1);
    Serial.print("  M3:"); Serial.print(ERR3, 1);
    Serial.print("  M4:"); Serial.println(ERR4, 1);

    Serial.print("STEER OUT  M1:"); Serial.print(OUT1, 0);
    Serial.print("  M2:"); Serial.print(OUT2, 0);
    Serial.print("  M3:"); Serial.print(OUT3, 0);
    Serial.print("  M4:"); Serial.println(OUT4, 0);

    Serial.print("DRIVE SPEED  M1:"); Serial.print(TargSPEED1, 0);
    Serial.print("  M2:"); Serial.print(TargSPEED2, 0);
    Serial.print("  M3:"); Serial.print(TargSPEED3, 0);
    Serial.print("  M4:"); Serial.println(TargSPEED4, 0);

    Serial.print("JOY  Drive(x,y):"); Serial.print(RawDriveX, 0); Serial.print(","); Serial.print(RawDriveY, 0);
    Serial.print("   Steer(x,y):"); Serial.print(RawSteerX, 0); Serial.print(","); Serial.println(RawSteerY, 0);

    printMotorState(1);
    printMotorState(2);
    printMotorState(3);
    printMotorState(4);
    Serial.println("------------------------------------");
  }
  delayMicroseconds(500);
}

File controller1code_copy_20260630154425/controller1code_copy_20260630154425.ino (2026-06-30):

#include <Arduino.h> 
#include <Wire.h> 
#include <SPI.h> 

#define DjoyXpin A0  
#define DjoyYpin A1  
#define SjoyXpin A3  
#define SjoyYpin A4  

#define W_REGISTER 0x20 
#define W_TX_PAYLOAD 0xA0 
#define FLUSH_TX 0xE1 

#define CONFIG_REG 0x00 
#define EN_AA_REG 0x01 
#define RF_SETUP_REG 0x06 
#define STATUS_REG 0x07 
#define TX_ADDR_REG 0x10 

const int SCK_PIN = 12; 
const int MOSI_PIN = 11; 
const int MISO_PIN = 10; 
const int CE_PIN = 9; 
const int CSN_PIN = 8; 

float DjoyXval = 0; 
float DjoyYval = 0; 
float SjoyXval = 0; 
float SjoyYval = 0; 
unsigned long printtime = 0; 

struct telemetry { 
  float DjoyX; 
  float DjoyY; 
  float SjoyX; 
  float SjoyY; 
}; 
telemetry joystickdata; 

void writeCommand(uint8_t COM) { 
  digitalWrite(CSN_PIN, LOW); 
  SPI.transfer(COM); 
  digitalWrite(CSN_PIN, HIGH); 
} 

void writeRegister(uint8_t REG, uint8_t value) { 
  digitalWrite(CSN_PIN, LOW); 
  SPI.transfer(W_REGISTER | REG); 
  SPI.transfer(value); 
  digitalWrite(CSN_PIN, HIGH); 
} 

void writeAddress(uint8_t REG, uint8_t* addr, int size) {
  digitalWrite(CSN_PIN, LOW);
  SPI.transfer(W_REGISTER | REG);
  for(int x = 0; x < size; x++){
    SPI.transfer(addr[x]);
  }
  digitalWrite(CSN_PIN, HIGH);
}

void DRIVEfetch(){ 
  DjoyXval = analogRead(DjoyXpin); 
  DjoyYval = analogRead(DjoyYpin); 
  if (DjoyXval >= 1832.5 && DjoyXval <= 2262.5) { DjoyXval = 2048; } 
  if (DjoyYval >= 1897.5 && DjoyYval <= 2197.5) { DjoyYval = 2048; } 
} 

void STEERfetch(){ 
  SjoyXval = analogRead(SjoyXpin); 
  SjoyYval = analogRead(SjoyYpin); 
  if (SjoyXval >= 1900.0 && SjoyXval <= 1980.0) { SjoyXval = 2048; } 
  if (SjoyYval >= 1950.0 && SjoyYval <= 2020.0) { SjoyYval = 2048; } 
} 

void setup() { 
  Serial.begin(115200); 
  delay(1000); 
  Serial.println("--- S3 Native Mapping Enforced ---"); 
  
  pinMode(DjoyXpin, INPUT); 
  pinMode(DjoyYpin, INPUT); 
  pinMode(SjoyXpin, INPUT); 
  pinMode(SjoyYpin, INPUT); 
  
  pinMode(CE_PIN, OUTPUT); 
  pinMode(CSN_PIN, OUTPUT); 
  digitalWrite(CE_PIN, LOW); 
  digitalWrite(CSN_PIN, HIGH); 
  
  analogReadResolution(12); 
  
  SPI.begin(SCK_PIN, MISO_PIN, MOSI_PIN, -1); 
  SPI.beginTransaction(SPISettings(4000000, MSBFIRST, SPI_MODE0)); 
  
  writeRegister(CONFIG_REG, 0x0E); 
  writeRegister(EN_AA_REG, 0x00);  
  writeRegister(0x03, 0x03);       
  writeRegister(0x04, 0x00);       
  writeRegister(0x05, 0x4C);       
  writeRegister(RF_SETUP_REG, 0x06); 
  
  uint8_t tx_addr[] = {0xE7, 0xE7, 0xE7, 0xE7, 0xE7};
  writeAddress(TX_ADDR_REG, tx_addr, 5); 
  
  Serial.println("--- nRF24L01 Transmitter Active ---"); 
} 

void loop() { 
  DRIVEfetch(); 
  STEERfetch(); 
  
  joystickdata.DjoyX = DjoyXval; 
  joystickdata.DjoyY = DjoyYval; 
  joystickdata.SjoyX = SjoyXval; 
  joystickdata.SjoyY = SjoyYval; 
  
  writeCommand(FLUSH_TX); 
  
  digitalWrite(CSN_PIN, LOW); 
  SPI.transfer(W_TX_PAYLOAD); 
  SPI.writeBytes((uint8_t*)&joystickdata, sizeof(joystickdata)); 
  digitalWrite(CSN_PIN, HIGH); 
  
  digitalWrite(CE_PIN, HIGH); 
  delayMicroseconds(130); 
  digitalWrite(CE_PIN, LOW); 
  
  writeRegister(STATUS_REG, 0x70); 

  if (millis() - printtime >= 250) { 
    printtime = millis(); 
    Serial.println("=== BROADCAST TELEMETRY METRICS ==="); 
    Serial.print("Drive Joystick X: "); Serial.println(joystickdata.DjoyX); 
    Serial.print("Drive Joystick Y: "); Serial.println(joystickdata.DjoyY); 
    Serial.print("Steer Joystick X: "); Serial.println(joystickdata.SjoyX); 
    Serial.print("Steer Joystick Y: "); Serial.println(joystickdata.SjoyY); 
    Serial.println("------------------------------------"); 
  } 
  delay(10); 
}

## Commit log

2026-06-10 Add files via upload
    photos of the swerves. this is version 4, 5 is about the same, except the housing is much better, and the measuements on the swerves themselves are tweaked a little
2026-06-25 Add files via upload
    swerve module CAD v5, fixed gear meshing issues, and made a chasis!
    [22t drive bevel.stl, 48tsteer gear real.stl, bottom shell.stl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]
2026-07-08 Add files via upload
    added newest STL files. this is the final design!
    [chasiss v1.stl]
2026-07-09 added step files to cad folder.
    [REAL swerves V6.step, chasiss v1.step]
2026-07-12 Update BOM.csv
    fixed bom.csv to exclude pcb stuff
    [BOM.csv]
2026-07-19 Add files via upload
    big code update! kinematics!
2026-07-19 Add files via upload
    added wiggle room to steer gears.
    [16t fixed.stl, fixed 10t.stl]
2026-07-23 Create controller PCB stuff
2026-07-23 Add files via upload
    added controller pcb stuff for horizons project
    [swervecontrollerPCBv1-B_Cu.gbr, swervecontrollerPCBv1-B_Mask.gbr, swervecontrollerPCBv1-B_Paste.gbr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]
2026-07-23 Add files via upload
    added robot pcb stuff for horizons project
2026-07-26 Add files via upload
    added newer controller pcb gerbers, now with almost all routing. still not ready to be purchased, adding so i can submit and qual intime for horizons polaris.
    [swervecontrollerPCBv1-F_Mask.gbr, swervecontrollerPCBv1-F_Paste.gbr, swervecontrollerPCBv1-F_Silkscreen.gbr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]
2026-07-26 Update README.md
    added newer pcb ss and renders
2026-07-28 Add files via upload
    added newer gerbers with correct routing. can now purchase pcb if wanted and it would function, but silkscreen labels need to be organized, will do that now.
    [swervecontrollerPCBv1-B_Cu (SIGNAL).gbr, swervecontrollerPCBv1-B_Mask.gbr, swervecontrollerPCBv1-B_Paste.gbr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]
2026-07-28 Add files via upload
    added final controller designs. now ready for purchase
    [swervecontrollerPCBv1-B_Cu (SIGNAL).gbr, swervecontrollerPCBv1-B_Mask.gbr, swervecontrollerPCBv1-B_Paste.gbr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]
2026-08-07 uploaded finished controller file to cpntroller pcb stuff.
    [swervecontrollerPCBv1-B_Cu (SIGNAL).gbr, swervecontrollerPCBv1-B_Mask.gbr, swervecontrollerPCBv1-B_Paste.gbr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]
2026-08-07 added finished robot pcb files to robvot pcb stuff
    [robotpcbv1-B_Mask.gbr, robotpcbv1-B_Paste.gbr, robotpcbv1-B_Silkscreen.gbr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]
